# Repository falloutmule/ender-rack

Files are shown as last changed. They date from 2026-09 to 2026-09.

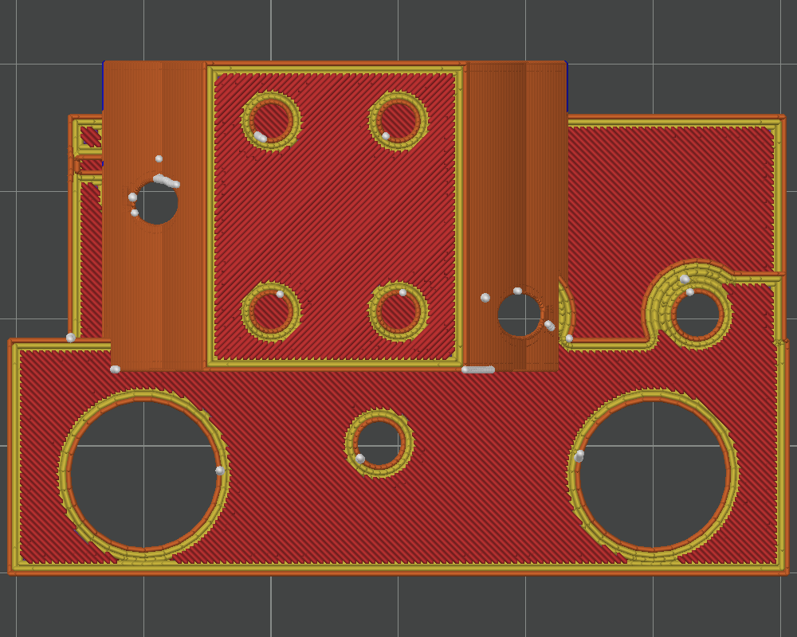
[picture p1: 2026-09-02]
evidence/renders/orca-r5-diagnostic/sliced-preview-top.png

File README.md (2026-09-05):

# EnderRack

EnderRack is an experimental high-lane-count adaptation of the [Annex Engineering TradRack](https://github.com/Annex-Engineering/TradRack) selector architecture to the complete X-axis motion system of an original/older Creality Ender-3-family donor printer.

The intended architecture retains the Ender X extrusion, V-wheel carriage, belt, motor, idler/tensioner, and endstop while replacing the stock TradRack MGN9 selector stage with a custom carriage-to-selector interface. The primary target is 15 lanes at the stock 17 mm TradRack pitch; 12 lanes remains the fallback generated from the same future parametric model.

## Current status

**Experimental. No production-ready release exists.**

The current article is **R7_ARCHITECTURE_V2_Candidate_001**. It has been printed and physically seats on the intact Ender carriage at the observed scope; a recurring boss-clearance overhang print defect did not prevent fit. No TradRack selector has been built yet, so full R7 physical PASS is **not** complete.

Next: [print and assemble the exact stock moving selector](docs/STOCK_SELECTOR_BUILD.md), then finish the R7 physical test. Production work and the 238 mm sweep remain gated. Earlier broad master/reproducibility claims require re-audit under the upgraded FreeCAD skill before production release.

Start with [CURRENT_STATE.md](docs/CURRENT_STATE.md), then read the complete [engineering handoff](docs/ENDER_RACK_HANDOFF.md).

## Validation approach

The project uses a physical-validation-gated workflow:

`reference CAD -> digital correlation -> cheap coupon -> physical PASS -> dependent geometry`

The earlier Ender-3 V2 reference failed this workflow and is archived as rejected evidence. The official original Ender-3 E-plate interface subsequently passed the R2 physical coupon test for the specific features exercised by that coupon.

## Upstream attribution

- [Creality3DPrinting/Ender-3](https://github.com/Creality3DPrinting/Ender-3)
- [Annex-Engineering/TradRack](https://github.com/Annex-Engineering/TradRack)

See [SOURCES.md](sources/SOURCES.md) and [LICENSE_NOTES.md](sources/LICENSE_NOTES.md). Complete upstream archives and assemblies are intentionally not vendored here. No EnderRack-wide license has been selected.

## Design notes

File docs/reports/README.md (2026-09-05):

# Report index

## Current scope

- [R7 V2 physical carriage fit](R7_V2_PHYSICAL_CARRIAGE_FIT.md): scoped owner-observed PASS; full selector fit NOT TESTED.
- [Stock selector build sheet](../STOCK_SELECTOR_BUILD.md) and [source/object evidence](STOCK_SELECTOR_SOURCE_EVIDENCE.json).
- `ENDER3_OFFICIAL_CARRIAGE_COUPON_R2.md`: physical interface evidence at its exercised scope.
- `ENDER3_OFFICIAL_CARRIAGE_REAUDIT.md`: historical reference correlation, subject to current scope and audit caveats.

## Retired design / diagnostic history

`ENDER_RACK_SELECTOR_INTERFACE_COUPON_R5.md`, `LIVE_ORCA_MCP_AUDIT_R5.md` and `legacy/` are historical evidence only. Do not print their G-code or reuse R5/22.25 mm relationships. Current state and upgraded-skill caveats are in [CURRENT_STATE.md](../CURRENT_STATE.md).

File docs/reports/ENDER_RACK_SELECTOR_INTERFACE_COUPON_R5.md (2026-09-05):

> Historical evidence only. Not the current design or print instruction. R5 relationships and 22.25 mm stand-off are retired; see docs/CURRENT_STATE.md.

# EnderRack selector-interface coupon R5

## Status

**DIGITAL PASS — PHYSICAL REAL-SELECTOR TEST REQUIRED**

Fabrication status: **PROVISIONAL — FIT-CHECK FABRICATION ONLY. DO NOT FABRICATE PRODUCTION PARTS.**

R5 supersedes R4. The user-identified failure location was the lateral ligament between the `X=0` wheel-clearance hole and the outside edge. R4 strengthened the lower ligament but accidentally left only approximately 0.25 mm laterally at this exact location.

## Correction

- Wheel-clearance radius: 5.75 mm.
- Minimum material from each wheel relief to its outside X edge: **5.00 mm**.
- Minimum material below each wheel relief: **5.00 mm**.
- R5 X extent: `-10.75 .. +50.75 mm`; the two wheel centers remain `X=0` and `X=40 mm`.
- The two full-height triangular selector-block gussets are retained. They support the cantilevered selector block and address a different load path from the wheel-edge ligament.
- The four selector-block holes remain intentionally blind Ø2.7 × 6.5 mm temporary M3 pilots.

## Verification

| Check | Result |
|---|---:|
| Bounding box | 61.500 × 22.250 × 40.550 mm |
| Volume | 23,459.308 mm³ |
| Topology | One valid solid |
| Circled lateral ligament | 5.000 mm, formerly 0.250 mm |
| Opposite wheel lateral ligament | 5.000 mm |
| Lower wheel ligament | 5.000 mm |
| Selector/coupon intersection | 0.000 mm³ |
| Coupon/wheel-envelope intersection | 0.000 mm³ |
| Coupon/conservative-belt intersection | 0.000 mm³ |
| R2 contact-layer missing volume | 0.000 mm³ |
| STEP BRep distance | 0.000 mm |
| STL bbox maximum delta | 7.63e-7 mm |
| STL facets | 1,520 |

Machine-readable verification: `../../work/ender-rack-inventory/ender_rack_selector_interface_coupon_r5_verification.json`.

## Artifacts

| Artifact | Bytes | SHA-256 |
|---|---:|---|
| `EnderRack_Selector_Interface_Coupon_R5.FCStd` | 17,536,897 | `B1EFD105F3B6D260C9538530F6B6DCBD37D0BAF2DC2C60AE2D66472AFE44FA49` |
| `exports/EnderRack_Selector_Interface_Coupon_R5.step` | 79,900 | `A471DE9772790A6DEC882545069C8CBD4F0CE840D9EA4DB57C37403A67E531C4` |
| `exports/EnderRack_Selector_Interface_Coupon_R5.stl` | 76,084 | `6070C29687531215B4A7D58FBD1C77B53CB3CB9BBB349A0F10DA72946EF2EBAC` |

Evidence renders:

- [Coupon-only isometric](screenshots/EnderRack_Selector_Interface_Coupon_R5_CouponOnly_Isometric.png)
- [Selector-facing](screenshots/EnderRack_Selector_Interface_Coupon_R5_CouponOnly_SelectorFacing.png)
- [Steel-contact](screenshots/EnderRack_Selector_Interface_Coupon_R5_CouponOnly_SteelContact.png)
- [Gusset plan](screenshots/EnderRack_Selector_Interface_Coupon_R5_CouponOnly_GussetPlan.png)

R5 is the current printable CAD source. R4 and earlier revisions are preserved but must not be used for the next fit check.

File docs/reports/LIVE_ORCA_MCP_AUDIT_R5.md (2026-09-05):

> Historical evidence only. Not the current design or print instruction. R5 relationships and 22.25 mm stand-off are retired; see docs/CURRENT_STATE.md.

# EnderRack R5 live Orca MCP slice audit

## Classification

- `LIVE_ORCA_MCP_PASS = PASS`
- `CURRENT_ENDERRACK_TEST_ARTICLE_SLICED = PASS`
- `READY_FOR_PHYSICAL_COUPON_PRINT = NO`

R5 is the only model on the live plate. R4 was explicitly removed before orientation and slicing.

## Source and placement

| Field | Value |
|---|---|
| STL | `C:\Users\fallo\Documents\Codex\2026-08-30\set-up-freecad-mcp-on-this\outputs\ender-rack\exports\EnderRack_Selector_Interface_Coupon_R5.stl` |
| STL SHA-256 | `6070C29687531215B4A7D58FBD1C77B53CB3CB9BBB349A0F10DA72946EF2EBAC` |
| Scale | 100% |
| Rotation | `(90, 0, 0)` degrees |
| World size | 61.500 × 40.550 × 22.250 mm |
| Placement | PASS; broad steel-contact face on bed; overflow 0 mm |

## Profiles and settings

- Printer: `Creality Ender-3 V2 0.4 nozzle`
- Filament: `Creality Generic PLA`
- Process: `0.20mm Standard @Creality Ender3V2`
- 0.20 mm layers; 3 walls; 4 top / 3 bottom layers; 15% crosshatch.
- Generated supports disabled. The retained triangular gussets provide modeled support for the selector-block overhang.
- Auto brim configured; skirt 0.

## Slice result

| Field | Result |
|---|---:|
| State | done, valid, 100% |
| Layers | 111 |
| Time | 1 h 29 m 59 s |
| Filament | 4,300.605 mm / 12.827 g |
| G-code bytes | 2,231,066 |
| G-code SHA-256 | `89EDF29DC7298A7ACCB3A3A6581DD54F20C12D2DCECBDBDB27B11E5AC0F54541` |

G-code: `C:\Users\fallo\Documents\Codex\2026-08-30\set-up-freecad-mcp-on-this\outputs\ender-rack\slice-results\live-orca-mcp-r5\EnderRack_Selector_Interface_Coupon_R5.gcode`.

Renders:

- [Oriented editor view](renders/post-orient-iso/render_plate-0.png)
- [Sliced isometric](renders/sliced-preview-iso/render_plate-0.png)
- [Sliced top](renders/sliced-preview-top/render_plate-0.png)
- [Sliced front/gussets](renders/sliced-preview-front/render_plate-0.png)

## Warning gate

Orca still reports level-3 warning `1000C001` / `bed_temperature_too_high_than_filament` because the native profile sets the bed and PLA vitrification values both to 60 °C. No material temperature was guessed or changed. Therefore this G-code is diagnostic evidence only and `READY_FOR_PHYSICAL_COUPON_PRINT` remains NO until an approved/spool-specific bed temperature is supplied and the part is freshly sliced.

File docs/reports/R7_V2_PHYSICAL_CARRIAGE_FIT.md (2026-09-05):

# R7 V2 scoped physical carriage-fit report

Recorded 2026-09-04 from the owner's direct report. No new photograph, measurement or physical inspection by the agent is claimed.

## Article and scope

`R7_ARCHITECTURE_V2_Candidate_001` has been printed. The Ender donor was NEVER disassembled: original X-axis hardware remains assembled/in place. The print seats on the real Ender carriage and visually aligns correctly. Unsupported boss-clearance overhang defects recurred, but did not prevent the observed carriage fit. No physical stock TradRack selector exists yet.

| Physical item | Result / scope |
|---|---|
| Correct Ender carriage face | PASS, owner-observed |
| R7 seats on real carriage | PASS, owner-observed |
| Exercised carriage hole relationship | PASS, observed scope only |
| Visible wheel-fastener relationship | PASS, observed scope only |
| Boss clearance sufficient for seating | PASS, observed scope only |
| Boss-clearance unsupported-overhang print quality | DEFECT NOTED; not a seating failure |
| Selector-side fit | NOT TESTED |
| Belt/clamp dynamic clearance | NOT TESTED |
| Selector rocking/translation/rotation | NOT TESTED |
| Physical stand-off / tool access / loaded stiffness | NOT ESTABLISHED by this report |
| Full R7 physical PASS | NOT YET |

## Digital record before printing — not a new certification

- v0.2: 19/19 checks PASS.
- Candidate installed-selector check: no positive-volume interference reported for evaluated valid geometry; invalid source gear remained UNVERIFIED.
- Cable-cover nominal CAD clearance: 2.950 mm.
- Left selector-body nominal CAD clearance: 2.211 mm.
- Minimum window-to-pilot material: 0.975 mm, not certified strength.
- Candidate signed stand-off: +15.0 mm; NOT physically validated.

Evidence: local `outputs/ender-rack-r7-architecture-v2-20260904/manifest.json`. Hashes below identify the staged article files at documentation time. The owner's identification of the exact printed candidate is accepted; this is not independent proof that a particular G-code file was executed.

| Staged artifact | SHA-256 |
|---|---|
| `EnderRack_R7_ARCHITECTURE_V2_Candidate_001.step` | `211dd737f815708c13a3b893db18f45a31397b28b6dba2ba8a8c46da538f51cc` |
| `EnderRack_R7_ARCHITECTURE_V2_Candidate_001.stl` | `3f976add9b47ac424422b241242a32665b2b3c038427b2abf115d3fc5488bbd3` |
| `EnderRack_R7_ARCHITECTURE_V2_Candidate_001_E_PLATE_FACE_DOWN.step` | `a7f6751d69ed0f7f1a405b19c930a977331c63427a5b542f0489232f2b75046b` |
| `EnderRack_R7_ARCHITECTURE_V2_Candidate_001_E_PLATE_FACE_DOWN.stl` | `ed7fb8c7fa278a73bb028d01aa4eb59f7af653fbbaf37fdf5f1b80f93a545afd` |
| `EnderRack_R7_ARCHITECTURE_V2_Candidate_001_Voxelab_Aquila_0p4_PLA_220C_55C.gcode` | `ef1b904e6d0c422540dd8a2c84c911b99e0e558ad9afdffdc095a9fb02fee2b1` |

## Upgraded-skill audit caveat

FreeCAD skill commit `7c26a143d2a6e4318724b96cc71c297f7424efa0` found stale embedded context metadata, 48 unreconciled shape occurrences, hidden live-session generator dependencies and ineffective declared parameters. Earlier broad reproducibility/whole-assembly claims require re-audit before production. This task did not redo that audit. These findings neither erase the owner's physical fit observations nor make untested selector behavior PASS.

## Repository baseline and scope

At task start the original checkout and current remote main were both `3e33980e440dbcbaa9c4284f37c8e8d96db4fa81` (observed, not imposed). Original checkout had unstaged `.gitignore`, `README.md`, `docs/CURRENT_STATE.md`, `docs/DECISIONS.md`, `docs/ENDER_RACK_FRESH_THREAD_PROMPT.md`, `docs/ENDER_RACK_HANDOFF.md`, and untracked `tools/`, `verification/`. No staged edits were observed.

A fresh clone of actual current remote main was used for this documentation update, preserving that original checkout and all its unfinished verifier/tool work. No reset, history rewrite, old-baseline checkout or CAD modification. This commit documents the true state; it does not represent unreviewed local tool changes as released software. R7 design files remain staged externally, identified by hashes rather than silently regenerated.

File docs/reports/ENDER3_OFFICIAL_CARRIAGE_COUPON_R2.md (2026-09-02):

# Ender-3 Official Carriage Coupon R2

## Status

**PHYSICAL FIT-CHECK PASS — 2026-09-01**

Fabrication status: **PROVISIONAL — FIT-CHECK FABRICATION ONLY. DO NOT FABRICATE PRODUCTION PARTS.**

The R1 coupon established good physical hole-pattern correlation but could not seat flat because it omitted relief for the two retained, raised hotend bosses. R2 changes only the coupon thickness and adds two coaxial boss pockets. The official plate reference, hole centers, wheel reliefs, V-notch, and motor-side cross are unchanged.

## Controlling dimensions

| Parameter | Value | Source |
|---|---:|---|
| Boss count | 2 | Physical observation / official assembly correlation |
| Boss center spacing | 14.000 mm | Official `E plate` BRep |
| Nominal boss-envelope input | 5.000 × 5.000 mm | Successful R2 design input; not an independent boss measurement |
| Pocket diameter | 5.500 mm | R2 geometry physically passed |
| Pocket depth | 5.200 mm | R2 geometry physically passed |
| Remaining floor | 1.200 mm | Fit-check design parameter |
| Coupon thickness | 6.400 mm | Pocket depth + floor |
| Through holes | Ø3.400 mm | Unchanged from R1 |

The physical seating result controls R2. The actual boss diameter and height were not independently measured, so the bosses remain clearance features rather than precision locators.

## Deliverables and verification

| Artifact | Bytes | SHA-256 |
|---|---:|---|
| `Ender3_Official_Carriage_FitCheck_R2.FCStd` | 27,839 | `5BFCCEA429CA99938D7D4C6E331EAB8527BCAC78F001BD873B6BBEB9D56F6B39` |
| `exports/Ender3_Official_Carriage_FitCheck_R2.step` | 43,823 | `CEB0FF7112BBFD7E4EDBA46C828C431A68E6472DCBF275925C5A48B8941B4AFC` |
| `exports/Ender3_Official_Carriage_FitCheck_R2.stl` | 46,284 | `E57E049BD18FC0F773B481B130ADC6976BBFF6C08E0909EE653916B485F3D88B` |
| `screenshots/Ender3_Official_Carriage_FitCheck_R2.png` | 21,190 | `52B99C8099405AFC99566D720B2FF6B1E23C5563844029B8EB56C96636DDB788` |

| Check | Result |
|---|---:|
| Bounding box | 56.500 × 32.900 × 6.400 mm |
| Topology | PASS — one valid solid |
| Save/close/reopen/recompute | PASS |
| Parameter object persisted | PASS |
| Reopened BRep pocket cylinders | PASS — 2 × R2.750, Z=0.000–5.200 mm |
| STEP BRep distance | `9.53e-17 mm` |
| STEP maximum bounding-box delta | `2.84e-14 mm` |
| STL maximum bounding-box delta | `5.72e-7 mm` |
| STL facets | 924 |
| RPC binding during generation | PASS — `127.0.0.1:9875` only |

Machine-readable verification: `../../work/ender-rack-inventory/ender3_official_fitcheck_r2_verification.json`.

## Print and physical test

Print the STL in PLA with a 0.4 mm nozzle and 0.2 mm layers. Import at 100% scale with no initial XY or hole compensation. Flip the part in the slicer so the two boss pockets face upward.

1. Put the V-notch toward the idler/tensioner side and the engraved cross toward the motor side.
2. Confirm both retained bosses enter the pockets without force.
3. Confirm all four pattern holes remain aligned.
4. Confirm the coupon seats flat against the steel face without rocking.
5. Hold or tighten it finger-snug and verify the datum marks cannot translate or rotate appreciably.
6. Confirm the wheel and separate gold belt hardware remain clear.

All six checks were reported as passing. The exact FCStd/STEP/STL and the received PASS photograph are preserved under `validated/ender3-carriage-interface-r2-pass/` with SHA-256 hashes.

No adapter, tensioner, selector transform, lane model, or production component was changed.

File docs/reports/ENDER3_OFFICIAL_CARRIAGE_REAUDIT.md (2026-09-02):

# Ender-3 Official Carriage Re-audit

## Superseding physical result — 2026-09-01

**R2 PHYSICAL FIT-CHECK PASS.** The official E plate is promoted as the controlling fabricated-fit reference only for the hole pattern, seating face, orientation, and boss-clearance relationship exercised by R2. The exact successful artifacts and PASS photograph are preserved under `validated/ender3-carriage-interface-r2-pass/`.

The R2 pockets are Ø5.5 × 5.2 mm deep. The 5 × 5 mm derivation values are successful nominal coupon inputs, not independently measured boss dimensions. The bosses are clearance features, not precision locators.

Static selector-interface work has resumed in `EnderRack_Selector_Interface_Coupon.FCStd`; physical real-selector testing is the current release gate. The historical re-audit narrative below is retained for traceability.

## Outcome

**PASS — the new physical photograph visually correlates with the official Creality Ender-3 `E plate` and complete carriage assembly when the correct plate face and orientation are used.**

This supersedes the earlier visual rejection. That rejection compared the wrong/opposite face and treated separate assembly hardware as if it had to be topology of the bare plate.

The official carriage remains at **physical fit-check candidate** status. R1 confirmed the hole pattern but failed to seat because it omitted relief for the two retained hotend bosses. Production adapter work remains blocked until the R2 coupon passes on the real machine.

## R1 physical result and R2 recovery — 2026-09-01

New physical evidence establishes a narrower result than either the original rejection or an unconditional pass:

- R1 official-CAD hole-pattern correlation: **PASS**;
- R1 flat seating: **FAIL — two retained raised hotend bosses obstruct the coupon**;
- boss removal: **not authorized**; they are treated as integral/retained carriage features;
- user-measured boss size: **Ø5.0 × 5.0 mm high**;
- gold belt hardware: separate assembly components, unchanged;
- R2 digital model/export validation: **PASS**;
- R2 physical seating: **PENDING**.

R2 adds two Ø5.5 × 5.2 mm-deep pockets on the same 14.0 mm source-derived centers. A 1.2 mm floor produces a 6.4 mm coupon thickness. Hole centers, Ø3.4 mm bores, wheel reliefs, outline, and datum marks are unchanged. See `ENDER3_OFFICIAL_CARRIAGE_COUPON_R2.md`.

## Physical evidence

Evidence file: `interface-recovery/evidence/physical_plate_rear_2026-08-31.jpg`

SHA-256: `AA6078E69A8E5B0F2A0D393312A3B4198EC32DB7804CC294B9D424CF7C9D427F`

The photograph is perspective evidence rather than a calibrated dimensional image. It supports correspondence of:

- overall rounded rectangular outline and central wheel tab;
- three-wheel triangular pattern;
- two 14 mm-spaced hotend-mount features;
- asymmetric auxiliary holes;
- wheel fasteners;
- two gold rear raised components associated with the belt.

## Face and orientation correspondence

| Physical/CAD view | Correspondence |
|---|---|
| Photograph | Rear / wheel-and-belt face of the physical carriage, with the central wheel tab upward |
| Imported model | `Part__Feature286`, label `E plate` |
| Matching CAD camera | Top view of the imported assembly with a 180° in-plane roll |
| Opposite face | Bottom view; hotend/radiator attachment face |

The combined render is [Ender3_Official_Carriage_FRONT-left_REAR-right.png](screenshots/Ender3_Official_Carriage_FRONT-left_REAR-right.png): **front is left; rear/photo-corresponding face is right**.

Individual renders:

- [Front / hotend face](screenshots/Ender3_Official_Carriage_FRONT_PhotoOrientation.png)
- [Rear / photo-corresponding face](screenshots/Ender3_Official_Carriage_REAR_PhotoOrientation.png)

## Complete-assembly feature audit

The apparent raised features are split between integral plate topology and separate assembly components:

| Feature | Official object(s) | Finding |
|---|---|---|
| Bare steel plate | `Part__Feature286` / `E plate` | One valid solid; controls fabricated-fit hole positions and plate outline |
| Two 14 mm-spaced hotend mounting bosses | Integral faces of `E plate` | Embossed/counterbored plate topology, not separate standoff objects |
| Hotend/radiator attachment screws | `Part__Feature663`, `Part__Feature664` | Separate `M3X16 Pan Head Screw003/004` objects inside `Sprinkler_assembly`; aligned to the integral boss centers |
| Gold raised rear pieces | `Part__Feature631`, `Part__Feature632` | Separate `Copper cover002/003` belt-end/crimp hardware; not hotend standoffs |
| Wheel hardware | `Part__Feature287–293`, `384–386` | Separate screws, washer, eccentric column, spacers, and nuts |

The official hotend-mount center spacing is exactly `14.000 mm`. The upper wheel-axis spacing is `40.000 mm`, and the eccentric axis is `40.200 mm` from the upper-wheel line.

Detailed machine-readable results: `../../work/ender-rack-inventory/ender3_official_carriage_reaudit.json`.

## Official-CAD fit-check coupon

Generated through FreeCAD MCP directly from cylindrical faces of the imported `E plate` BRep:

- `Ender3_Official_Carriage_FitCheck.FCStd`
- `exports/Ender3_Official_Carriage_FitCheck.step`
- `exports/Ender3_Official_Carriage_FitCheck.stl`
- [Coupon render](screenshots/Ender3_Official_Carriage_FitCheck.png)

The coupon is a rear-face pattern overlay, not an adapter. It contains:

- both 14 mm-spaced hotend-mount holes;
- both asymmetric auxiliary holes visible in the official plate pattern;
- reliefs derived from the installed upper-wheel fastener envelopes;
- a V-notch marking the official idler/tensioner side;
- an engraved cross marking the official motor side;
- no TradRack, selector, tensioner, or production structure.

Dimensions and digital verification:

| Check | Result |
|---|---:|
| Coupon bounding box | 56.500 × 32.900 × 2.000 mm |
| Selected source-derived holes | 4 |
| Nominal source bores | Ø3.000 mm |
| Printed clearance bores | Ø3.400 mm |
| Upper-wheel hardware relief radius | 5.750 mm |
| Coupon topology | PASS — one valid solid |
| Save/close/reopen/recompute | PASS |
| STEP BRep distance from FCStd | `7.42e-14 mm` |
| STEP maximum bounding-box delta | `2.84e-14 mm` |
| STL maximum bounding-box delta | `5.72e-7 mm` |
| STL facets | 716 |

Hashes:

| File | Bytes | SHA-256 |
|---|---:|---|
| `Ender3_Official_Carriage_FitCheck.FCStd` | 24,627 | `C4175A7755547D9A2DB97604E42E94CEBF9F6A8A2A187A6B5E917BBEA12FC36B` |
| `Ender3_Official_Carriage_FitCheck.step` | 40,021 | `900BCF148CB706E4676D125A6EC9DDD5D4752B4ED1A51B1910FBE4BFE2A1C3CD` |
| `Ender3_Official_Carriage_FitCheck.stl` | 35,884 | `946469AD81B78B434278A1850FFD6336486A68D2CAEA35CC339B86701350E609` |

Machine-readable verification: `../../work/ender-rack-inventory/ender3_official_fitcheck_verification.json`.

## R2 physical fit-check instructions

Fabrication status: **PROVISIONAL — FIT-CHECK FABRICATION ONLY. DO NOT FABRICATE PRODUCTION PARTS.**

Do not reprint R1. Print `exports/Ender3_Official_Carriage_FitCheck_R2.stl` cheaply in PLA with a 0.4 mm nozzle and 0.2 mm layers. Do not apply slicer XY/hole compensation on the first test. Import at 100% scale and flip the part so the two boss pockets face upward.

Test against the same rear/photo-corresponding face used for the re-audit:

1. Orient the V-notch toward the official idler/tensioner side and the engraved cross toward the motor side.
2. Confirm both retained bosses enter the new pockets without force.
3. Confirm the two large open reliefs clear the installed upper-wheel fastener hardware.
4. Confirm both hotend-mount holes align and accept pins/fasteners finger-snug without forcing.
5. Use the two auxiliary holes as positional pattern checks; do not assume they are threaded or force fasteners into them.
6. Confirm the coupon seats flat without rocking.
7. With the coupon held finger-snug, confirm the V-notch/cross cannot translate or rotate appreciably relative to the wheel-axis pattern.

PASS promotes the official `E plate` to the EnderRack carriage reference. FAIL stops adapter work and requires recording the exact R2 interference and remeasuring the controlling feature before any geometry is changed.

No `EnderRack_15Lane_Ender3.FCStd`, production adapter, or tensioner redesign was created during this re-audit.

## Project state

**ENDER RACK ARCHITECTURE PRESERVED — R1 HOLE PATTERN PASS / BOSS SEATING FAIL — R2 DIGITAL PASS — R2 PHYSICAL FIT-CHECK PENDING**

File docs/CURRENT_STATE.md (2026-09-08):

# EnderRack current state

Updated 2026-09-07. **Current article: R7_ARCHITECTURE_V2_Candidate_001. Printed; scoped carriage fit PASS; full R7 physical PASS NOT YET. Controlling selector remains stock TradRack R1.**

## Physical state — owner report

The Ender donor was NEVER disassembled. Original Ender X-axis hardware remains assembled/in place. The exact R7 V2 print seats on the real Ender carriage and visually aligns correctly. The boss-clearance unsupported-overhang print defect recurred but did not prevent observed seating. No physical TradRack selector has been built yet.

Correct carriage face, seating, exercised carriage-hole relationship, visible wheel-fastener relationship, and boss-clearance seating function PASS only at the observed scope. Selector fit, belt/clamp dynamic clearance, rocking/translation/rotation and complete physical validation are NOT TESTED. See [scoped physical report](reports/R7_V2_PHYSICAL_CARRIAGE_FIT.md).

## Recorded digital state before printing

Verifier v0.2: 19/19 checks PASS. The candidate's complete installed selector check reported no positive-volume interference among evaluated valid geometry; invalid source gear remained UNVERIFIED. Cable-cover nominal clearance 2.950 mm; left body 2.211 mm; minimum window-to-pilot material 0.975 mm. These are recorded CAD results, not physical measurements or strength proof. Stand-off +15.0 mm remains a candidate relationship.

## Audit caveat

Installed upgraded FreeCAD skill: commit `7c26a143d2a6e4318724b96cc71c297f7424efa0`. Earlier broad master-context/reproducibility claims preceded discovery of stale embedded context metadata, 48 unreconciled shape occurrences, hidden live-session generator dependencies and ineffective declared parameters. Those claims require re-audit before production release. The audit caveat does not erase observed physical carriage fit or promote invalid geometry to clear. No whole-master re-audit was performed for this selector-build task.

## Immediate next action

Build the exact [stock moving selector](STOCK_SELECTOR_BUILD.md), then finish R7's physical test. The [Binky/EREC comparison](MODDED_SELECTOR_COMPARISON.md) did not establish an evidence-complete modded R7 relationship: the primary Fusion assembly cannot be authoritatively decoded in FreeCAD, and the STEP fallback contains an invalid encoder-left body overlapping the R7 region. Stock remains controlling; R7 remains frozen. Measure the spare Ender stepper and both mirrored BMG-clone internals before buying replacements.

R7 architecture/frame, four selector axes and +15 mm candidate placement remain frozen. R5 and its 22.25 mm relationship are retired. R6/R6R1 geometries are rejected. R6R2 DIGITAL_OBJECT PASS; PHYSICAL TEST WAIVED BY OWNER, NOT A PHYSICAL PASS. Historical solids are evidence, not construction inputs.

## Downstream gate

Full R7 physical PASS precedes production adapter and full 238 mm selector sweep. Fifteen lanes at 17 mm pitch remains the goal; twelve lanes the fallback. First/middle/last master positions were context views, not a validated sweep. No redesign, slicing, printing command, production work or sweep was performed in this documentation task.

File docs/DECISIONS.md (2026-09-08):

# EnderRack durable decisions

Current as of 2026-09-07; supersedes conflicting historical status language, not historical evidence.

1. Mechanical donor is the original/older Ender-3-family X-axis. It was NEVER disassembled. Aquila identifies the print machine only.
2. Community Ender-3 V2 fit geometry is retired. Official Creality E-plate + scoped R2 physical evidence establish the interface and seating face.
3. Preserve interfaces, physical facts and known failures independently from disposable coupon solids. Required empty clearances do not require reproducing R2 pocket shelves.
4. R5 wrong-face relationship, 22.25 mm stand-off and legacy V-notch are retired. R6/R6R1 architecture is rejected. R6R2 digital PASS has an owner-waived physical witness, never physical PASS.
5. Current article is R7_ARCHITECTURE_V2_Candidate_001, with two named exterior-open access windows, fixed selector axes/orientation and +15 mm candidate stand-off. This documentation task changes no geometry.
6. R7 V2 is printed and passes the observed carriage seating/interface scope. Unsupported boss-clearance overhang print quality is defective but did not prevent seating. No selector exists physically; full R7 physical PASS is outstanding.
7. Keep digital checks, construction assertions, physical evidence and audit caveats separate. An invalid source gear stays UNVERIFIED, never zero collision. Earlier broad master reproducibility claims need the upgraded-skill re-audit before production.
8. The 0.25 mm demonstrated weak-ligament failure is known bad; 5 mm is a design preference, not an invented universal minimum. A passing STEP is not strength proof.
9. Use existing verifier v0.2 only for its supported operators. No verifier expansion, CAD redesign or audit rerun in this selector-build task.
10. Build one stock default moving selector: 9 mm C-cart middle, 10x10 two-hole right, Micro-Fit wiring holder, FT1117M servo and conventional BMG filament-drive mechanism. Keep the filament-drive motor; omit the replaced stock MGN translation system.
11. Source authority is pinned TradRack `f89dc0b115adfc49195d782c5d7ecd348a574891`, its default STEP, STL files and official manual; the linked live BOM snapshot is separately dated/hashed. Unresolved discrepancies must remain visible.
12. Stock selector printing follows upstream ASA/PC guidance, not PLA coupon settings. R7 service sequence: mount/tighten carriage adapter first, then mount selector finger-snug using verified engagement.
13. Full R7 physical PASS gates production adapter and 238 mm sweep. Target 15 lanes at 17 mm pitch; 12-lane fallback. Context lane views are not a collision sweep.
14. Read actual repository HEAD/dirty state; preserve user work and history. Happy Hare/Klipper and donor electronics remain future plans, not commissioned hardware.
15. The 2026-09-07 Binky/EREC comparison does not change the controlling selector. Printables 1385926 is the preferred physical-build mod candidate, but its F3D cannot be decoded into authoritative assembly BReps/placements by the installed FreeCAD toolchain. Printables 963410 shows positive nominal clearance for valid Binky/cutter bodies, but an invalid overlapping encoder-left body keeps the complete result UNVERIFIED. Preserve this result; do not infer clear from invalid geometry.
16. Build stock R1 first. Before buying a filament-drive motor or genuine Bondtech internals, measure the spare Ender stepper and both mirrored BMG-clone internals. Housing handedness is not a reason to reject reusable internals.

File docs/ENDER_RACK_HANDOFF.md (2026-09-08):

# EnderRack engineering handoff

Read [CURRENT_STATE.md](CURRENT_STATE.md), [R7 V2 physical report](reports/R7_V2_PHYSICAL_CARRIAGE_FIT.md), [modded-selector comparison](MODDED_SELECTOR_COMPARISON.md), then [STOCK_SELECTOR_BUILD.md](STOCK_SELECTOR_BUILD.md).

## Controlling facts

- Original/older Ender-3-family mechanical donor: intact X-axis, never disassembled. Aquila is the coupon print machine, not the mechanical reference.
- Official Creality E-plate and scoped R2 physical interface evidence establish the carriage interface. Preserve its established physical face correlation.
- ENDER_INTERFACE v1 and authenticated stock TradRack selector interface are the inputs; historical coupon solids are evidence only.
- R7_ARCHITECTURE_V2_Candidate_001 has been printed and fits the carriage at the owner-observed scope. Its recurring boss-clearance overhang defect is recorded, not redesigned here.
- No stock selector exists physically yet. Build the resolved 9 mm C-cart / 10x10-right / Micro-Fit / FT1117M moving selector, excluding the replaced stock MGN motion stage.
- Stock R1 remains controlling after the Binky/EREC comparison. Modded R7 compatibility is UNVERIFIED, not failed-clear: the preferred F3D cannot be placed authoritatively in FreeCAD and the STEP reference contains an invalid encoder-left body in the R7 region.
- Measure spare Ender stepper and both mirrored BMG-clone internals before buying the filament-drive motor or genuine Bondtech parts.
- +15.0 mm selector stand-off is candidate, not measured/validated. Full R7 physical PASS has not occurred.

## Preserve architecture and evidence

R7 V2 has two named exterior-open carriage-access reliefs and one main load path. Do not silently change topology, pilots, orientation, base or stand-off. No historical coupon contours as construction input. The 5 mm clearance preference is not a fabricated physical requirement; the 0.975 mm reported minimum window-to-pilot material is not a strength certification.

The prior 19/19 v0.2 result and valid-component clearance findings are historical digital evidence. Invalid source gear remains UNVERIFIED. Upgraded skill `7c26a143d2a6e4318724b96cc71c297f7424efa0` identified stale master metadata, 48 unreconciled occurrences, live-session dependencies and ineffective parameters. Re-audit broad reproducibility/whole-assembly claims before production, without erasing the scoped physical result.

## Next physical sequence

Assemble the stock moving selector from the build sheet. Tighten R7-to-Ender fasteners before installing the selector. Determine safe selector screw engagement; finger-snug only. Record all R7 physical checks, including actual stand-off, motion of the mounted joint and real hardware/tool clearances. No powered commissioning yet. R7 physical PASS unlocks production adapter and 238 mm sweep; context views do not unlock them.

## Repository handling

Always read actual HEAD and dirty state; do not reset to a remembered baseline. The 2026-09-04 documentation update was made in a clean current-remote clone to preserve pre-existing verifier/tool edits in the original dirty checkout. See the physical report for baseline and change scope. Upstream TradRack remains pinned to `f89dc0b115adfc49195d782c5d7ecd348a574891`; do not casually update CAD or variants.

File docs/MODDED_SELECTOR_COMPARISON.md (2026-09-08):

# Modded selector comparison

Updated 2026-09-07. **Selected build: authenticated stock TradRack R1 moving selector.** The Binky and EREC/cutter variants remain useful future options, but neither has an evidence-complete R7 compatibility result. R7 geometry was not changed.

Repository baseline before this comparison update: `875ec737eb1b558d64b7c11aca0a0677c10a04d2`, clean working tree. History was not reset or rewritten.

## Decision

| Option | Evidence | R7 result | Decision |
|---|---|---|---|
| A. Stock TradRack R1 | Pinned upstream default STEP, pinned STLs, official BOM/manual; existing complete-selector R7 check | DIGITALLY COMPATIBLE at the recorded candidate relationship; invalid stock gear remains UNVERIFIED; physical selector test outstanding | **BUILD THIS** |
| B. R1 + Binky | Printables 963410 complete STEP reference; valid Binky bodies evaluated in the stock-R1 frame | **UNVERIFIED**: Binky rack clears R7 by 3.030 mm and valid encoder-right body by 1.874 mm, but encoder-left is an invalid source BRep whose bounding box overlaps the R7 region | Do not print as the controlling selector |
| C. R1 + Binky + EREC cutter | Printables 1385926 editable Fusion source and physical-build evidence; 963410 STEP reference; 985791 STL cutter evidence | **UNVERIFIED**: primary Fusion archive cannot be decoded into authoritative BReps/placements by the installed FreeCAD toolchain; fallback STEP retains the invalid overlapping encoder-left body. Valid cutter-reference bodies did not positively intersect R7; one modeled MG996R servo body is only 0.172 mm clear | Do not print as the controlling selector |

This is not a physical PASS for any selector. The existing R7 carriage-side fit remains scoped physical evidence only.

## Sources inspected

- Official authority: Annex Engineering TradRack commit `f89dc0b115adfc49195d782c5d7ecd348a574891`, `CAD/Trad_Rack_R1_2024-03-04_STEP.7z` -> `trad_rack_(default).STEP`.
- Primary mod candidate: [TradRack Binky+EREC Integration](https://www.printables.com/model/1385926-tradrack-binkyerec-integration-trianglelabs-partne), RedHeadnDead, CC BY, published 2026-04-26. It supplies 17 STL files and `Tr-B-EREC.f3d` (`a8720d880db6ff864ebedba0aa5a94ab2e2b68de9ed46b5c23b8c72be6046d12`). The author reports a physical build and describes a stronger Binky mount, removable Binky/EREC, a larger selector servo, and an inverted EREC gear assembly.
- Assembly-CAD reference: [TradRack MMU + Binky + Filament Cutter + User Mods CAD Model](https://www.printables.com/model/963410-tradrack-mmu-binky-filament-cutter-user-mods-cad-m), BakedBean3D, GPL-2.0. It supplies Binky-only and Binky+EREC STEP assemblies. Its author explicitly says the modeled Binky integration was not printed or used.
- Cutter implementation evidence: [TradRack Encoder + Cutter Mod](https://www.printables.com/model/985791-tradrack-encoder-cutter-mod), Pham Tuan, GPL-2.0. It supplies STL variants, not an editable/assembled source; the page identifies a retained gate switch, V/623 encoder options, EREC integration, and changed cable position.
- Binky upstream: Marc Neuhaus's `EnragedRabbitProject/usermods/Binky`. Binky replaces the optical encoder with an EE-SX398-based PCB and filtered slotted wheel, using a BMG idler gear, its needle bearings and 3 x 20 mm pin. It remains mounted on the moving selector and adds a three-wire encoder connection.
- Cutter upstream: KevinAkaSam/BioKeks EREC Beta 7.0. It is a servo-actuated, selector-mounted inline cutter behind the encoder. A scalpel/Exacto blade sits on a swinging arm carrying the ECAS fitting; opening permits tip feed, closing cuts, and the separated tip falls out. Happy Hare requires its EREC add-on configuration and cutter action; firmware commissioning is later work.

The repository [source manifest](reports/MODDED_SELECTOR_SOURCE_MANIFEST.json) anchors the official files and principal assemblies. The complete 44-file Printables inventory, including every STL hash and file ID, is preserved in external scratch as `source_provenance_manifest.json` beside the downloaded sources.

## Frame and R7 check

The mod reference was correlated to stock R1 first, then carried through the existing stock-R1-to-E relationship. No independent Ender face was inferred.

`T_E<-MOD`, millimetres, column-vector convention:

```text
[ 1  0  0  -20.375000000 ]
[ 0  0  1   25.022256770 ]
[ 0 -1  0  -52.031656654 ]
[ 0  0  0    1.000000000 ]
```

The rotation is orthogonal, right-handed, determinant +1, unit scale and no shear. It maps the modded 9 mm/C-cart middle-carriage reference back to the authenticated stock selector frame; R7 remains at +15.0 mm candidate stand-off with its four frozen pilot axes.

### Numeric evidence

| Reference occurrence | Source validity | R7 intersection | R7 distance | Disposition |
|---|---:|---:|---:|---|
| `BinkyRack wgate switch encoder mount (Exerqtor_82339)` | valid | 0.000 mm3 | 3.030 mm | clear in this reference placement |
| `Encoder Right (2)(Mirror)` | valid | 0.000 mm3 | 1.874 mm | clear, small nominal margin |
| `Encoder Left (2)(Mirror)` | **invalid** | not evaluated as zero | overlapping bounding region | **UNVERIFIED** |
| EREC/cutter valid bodies | valid | no positive-volume R7 intersection found | nonblocking except servo below | reference only |
| `servoMotorMG996R (1)(Mirror)` | valid | 0.000 mm3 | 0.172 mm | technically clear, not a practical validated margin |

Stock MGN carriage, rail screws and lane-module occurrences present in the reference STEP were excluded because EnderRack replaces that translation system. They are not selector collisions. Unchanged stock selector geometry uses the authenticated official R1 source rather than invalid duplicate imports from the community STEP.

The result is not promoted to `MODDED SELECTOR / R7 INTERFACE DIGITALLY COMPATIBLE`: the invalid encoder-left source body overlaps the only region where a collision would matter. Kernel/source failure is UNVERIFIED, never zero.

## Part replacement map

The primary mod's native assembly membership cannot be recovered from the F3D without Autodesk ShapeManager support. Filename-only mappings below are intentionally not promoted to authoritative replacements.

| Official R1 part | Primary mod evidence | Status |
|---|---|---|
| cable cover | `[a] Tr-B-EREC_Cable Chain Mount.stl`; no stock-named cable cover supplied | replacement relationship **UNRESOLVED** |
| carriage left | `Tr-B-EREC_Carriage - Left.stl`, `Carriage - Left Arm.stl` | MODIFIED/REPLACED family; exact occurrence split UNRESOLVED |
| carriage middle, 9 mm/C-cart | `Tr-B-EREC_Carriage.stl` | likely modified integration body, but pilot/mating correspondence **UNVERIFIED** |
| carriage right, 10x10 | `Carriage - Right Arm.stl`, cable-chain mount | MODIFIED/REPLACED family; exact 10x10 correspondence **UNVERIFIED** |
| Micro-Fit holder | no unambiguous matching mod file | UNRESOLVED; do not infer removal |
| servo horn | `[a] Tr-B-EREC_Servo Horn.stl` plus selector servo spacers/cage | REPLACED for larger-servo design |
| arm; gear casings left/right; motor plate; NEMA17 spacer; tensioner collar | no replacements supplied by name | stock carry-over is plausible from author instructions, but assembly membership UNVERIFIED |
| filament-drive NEMA17 and conventional BMG drive | author says follow TradRack BOM; no replacement motor-drive file | unchanged function; exact hardware envelope UNVERIFIED |
| Binky encoder | encoder left/right, Binky PCB/slotted wheel implied by source description | ADDED on moving selector |
| EREC cutter | cutter arm, servo gear/rig/cage, tip catcher | ADDED inline cutter architecture |

## What Binky adds

Binky provides direct filament-motion feedback with a slotted wheel and filtered optical PCB. It adds encoder wiring and changes the moving-selector/cable envelope. The standard Binky mechanism uses BMG-style idler components, so parts from the two mirrored BMG clones are worth measuring. Housing handedness alone does not disqualify internals. Binky is not selected yet because the complete R7 relationship remains UNVERIFIED.

## What the cutter adds

EREC Beta 7 adds a second servo, printed cutter/encoder support, servo gear, swinging ECAS cutter arm, blade, fasteners/inserts and a tip catcher. It adds a blade consumable, debris path, cable load and Happy Hare add-on configuration. It is not required to establish initial stock EnderRack operation, and its integration changes the selector envelope checked by R7.

## Build selection and next action

Print and build the exact stock R1 selector in [STOCK_SELECTOR_BUILD.md](STOCK_SELECTOR_BUILD.md). First measure the spare Ender stepper and both mirrored BMG clones using the reuse checklist in that document; do not buy the filament-drive motor or genuine Bondtech internals until those measurements are compared. Mount the completed stock selector finger-snug to the already printed R7 and finish the physical R7 checklist before selecting Binky, cutter, production adapter or the 238 mm sweep.

## External inspection artifacts

The source downloads, complete provenance manifest, comparison FCStd and four rendered views are staged outside the Git tree at:

`C:/Users/fallo/Documents/Codex/2026-09-02/files-pasted-by-the-user-continue/EnderRack-Modded-Selector-Comparison-20260907/`

The FCStd is a viewing derivative, not source authority. R7 is frozen; stock R1 is blue, Binky is orange, EREC is purple, and invalid source bodies are red.

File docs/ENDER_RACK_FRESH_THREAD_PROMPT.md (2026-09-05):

# Fresh-thread handoff

Continue EnderRack by first reading CURRENT_STATE.md, ENDER_RACK_HANDOFF.md, reports/R7_V2_PHYSICAL_CARRIAGE_FIT.md and STOCK_SELECTOR_BUILD.md. Read actual Git HEAD and dirty state; preserve edits and history.

The Ender X-axis is intact and was never disassembled. R7 V2 Candidate001 is printed and physically seats at the observed carriage scope, with a recurring unsupported-overhang defect. The stock selector has not been built. Full R7 physical PASS is NOT YET. Preserve frozen R7 architecture and +15 mm candidate relationship. Do not resume retired R5 geometry, 22.25 mm assumptions or a coupon slicing task.

Build the stock selector from pinned source evidence, resolving the explicit procurement/engagement caveats before dependent assembly. No production or 238 mm sweep before full R7 physical PASS. Earlier whole-master/reproducibility claims require upgraded-skill re-audit before production, not erasure of physical observations.

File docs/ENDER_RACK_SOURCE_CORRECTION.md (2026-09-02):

# EnderRack Source Correction

## Superseding milestone — 2026-09-01

**OFFICIAL ENDER-3 CARRIAGE INTERFACE — PHYSICAL R2 FIT-CHECK PASS**  
**15-LANE ENDER RACK — STATIC SELECTOR INTERFACE DESIGN RESUMED**

The exact successful R2 FCStd/STEP/STL and physical PASS photograph are preserved under `validated/ender3-carriage-interface-r2-pass/`. The official E plate now controls fabricated fit only for the physically validated hole pattern, seating face, orientation, and boss-clearance relationship. Bosses remain clearance features rather than locating datums.

`EnderRack_Selector_Interface_Coupon.FCStd` is the new static secondary coupon. It digitally passes reopen/export and local selector/wheel/conservative-belt checks. Physical real-selector testing is now the release gate. See `ENDER_RACK_SELECTOR_INTERFACE_COUPON.md`. No 238 mm sweep, lane structure, tensioner redesign, or production adapter was generated.

## Current project state

Historical state below is retained for traceability; it is superseded by the milestone above.

The Ender-3 V2 carriage reference remains rejected. The real plate corresponds closely to the official `E plate` when the correct rear face and in-plane orientation are used. Physical R1 testing confirmed the official hole pattern but found that the coupon could not seat over the two retained raised hotend bosses. R2 preserves the pattern and adds pockets from user-measured Ø5 × 5 mm boss geometry. See `ENDER3_OFFICIAL_CARRIAGE_REAUDIT.md` and `ENDER3_OFFICIAL_CARRIAGE_COUPON_R2.md`. No adapter, selector transform, production EnderRack derivative, or tensioner redesign was generated.

## Decision summary

| Question | Result | Evidence / effect |
|---|---|---|
| Was the prior V2 work preserved? | PASS | 30 immutable copies are recorded in `archive/rejected-ender3v2-reference/archive_manifest.json`; originals remain in place. |
| Was official Ender-3 CAD used? | PASS | Exact repository commit and Git blob identities are recorded below. |
| Did the complete STEP import through FreeCAD MCP? | PASS | 1,243 objects; 1,178 shape-bearing objects; no null shapes, invalid topology, or invalid placements. |
| Did the FCStd survive save/close/reopen/recompute? | PASS | 1,243 objects and the embedded provenance record persisted. |
| Was the official X gantry isolated? | PASS | `EnderRack_Ender3_Official_Concept.FCStd` contains the `Ender3_X_Gantry_Official` group and 33 self-contained, valid shape copies. |
| Does the official plate match the real plate? | **PASS — visually provisional** | New photo evidence matches the rear/photo-oriented official `E plate` outline, three-wheel pattern, auxiliary holes, integral hotend bosses, and separate belt hardware. Physical dimensions are still gated by the coupon. |
| Did R1 correlate physically? | **CONDITIONAL PASS** | Hole pattern aligns; flat seating failed solely because the retained raised bosses lacked relief pockets. |
| Was an R2 printable coupon exported? | **PASS — digital** | Versioned FCStd, STEP, and STL retain R1 coordinates and add two physically dimensioned boss pockets. Physical R2 seating remains pending. |

## Rejected Ender-3 V2 work

Archive: `archive/rejected-ender3v2-reference/`

Status label: **REJECTED — WRONG MACHINE REFERENCE — ENDER-3 V2**

The archive contains 30 files, including the original community V2 STEP, V2 reference FCStd, V2-based concepts/designs, failed coupon FCStd/STEP/STL, screenshots, audits, and recovery records. `archive_manifest.json` records each source path, archived path, byte size, source timestamp, and SHA-256. The archived files are read-only copies; the originals were not deleted or modified.

New physical evidence is preserved as `interface-recovery/evidence/physical_plate_rear_2026-08-31.jpg`, SHA-256 `AA6078E69A8E5B0F2A0D393312A3B4198EC32DB7804CC294B9D424CF7C9D427F`.

## Official source provenance

Repository: [Creality3DPrinting/Ender-3](https://github.com/Creality3DPrinting/Ender-3)

Repository commit: `88c7758cea9d0d00a54fdb238bedb3b33425f409`

| Source | Repository path / identity | Bytes | SHA-256 | Local status |
|---|---|---:|---|---|
| `Ender3.STEP` | [`Ender-3 Mechanical/STP/Ender3.STEP`](https://github.com/Creality3DPrinting/Ender-3/blob/88c7758cea9d0d00a54fdb238bedb3b33425f409/Ender-3%20Mechanical/STP/Ender3.STEP); Git blob `30c9b930c0cc094b4d02acd72d71d835d7225c72` | 29,867,304 | `7E868F30A44F0E6B1DD0DAF8AF1D7810AD9A754CC6FA066F6EF4D2B81E3297AF` | Immutable/read-only |
| `Ender 3.f3d` | [`Ender-3 Mechanical/F360/Ender 3.f3d`](https://github.com/Creality3DPrinting/Ender-3/blob/88c7758cea9d0d00a54fdb238bedb3b33425f409/Ender-3%20Mechanical/F360/Ender%203.f3d); Git blob `998bd68bf940c3bd691fa9d7ead705bfa401e323` | 6,344,736 | `95909A53CCFAC0E4F3EFEC9B964780D5602B453F441274DFEBB4B5D18C2BC726` | Recorded and immutable/read-only; not imported |

Retrieved: `2026-08-31T18:06:44-06:00` (America/Denver).

Local source directory: `work/sources/ender-rack/official-ender3/`

The prior community Ender-3 V2 model was not used as a fallback.

## FreeCAD MCP import and digital validation

Deliverable: `Ender3_Official_reference.FCStd`

| Check | Result |
|---|---|
| MCP/RPC transport | PASS — listener verified at `127.0.0.1:9875`; no remote/wildcard binding |
| Imported document objects | 1,243 |
| Shape-bearing objects | 1,178 |
| Null geometry | 0 |
| Invalid topology | 0 |
| Invalid placements | 0 |
| Save/close/reopen/recompute | PASS |
| Reopened object count | 1,243 |
| Embedded source provenance | PASS |
| Obvious incomplete assembly | Not observed; frame, axes, belts, motors, endstops, bed, electronics, and hotend/fan assembly are present |

Intentional construction axes and origins were accepted. Their mathematically infinite bounding boxes were excluded from physical size calculations; they are not geometry failures.

Inventory: `../../work/ender-rack-inventory/ender3_official_import.json`

FCStd SHA-256: `56668B32302299CBFA9208167C4F50BA45C22BB1780F3A8E5E185FEA3840C75B`

## Official X carriage audit

The official assembly labels the sole carriage-plate candidate `E plate` (`Part__Feature286`). It is adjacent to the three X-stage V-wheels, X extrusion, X belt, hotend/fan assembly, belt clamps, motor, and endstop.

Measured directly from the imported BRep:

| Feature | Official CAD value |
|---|---:|
| Overall `E plate` bounding box | 64.000 × 63.949 × 27.400 mm |
| Plate base thickness between principal parallel faces | 2.500 mm |
| Upper wheel-axis center distance | 40.000 mm |
| Upper wheel line to lower/eccentric axis | 40.200 mm |
| Upper wheel through-hole diameter | 5.000 mm |
| Lower/eccentric through-hole diameter | 7.200 mm |
| Shape validity | PASS |

The official front view is [Ender3_Official_E_Plate_Face.png](screenshots/Ender3_Official_E_Plate_Face.png). The isolated stage is [Ender3_X_Gantry_Official.png](screenshots/Ender3_X_Gantry_Official.png).

### Physical correspondence gate — re-audited

New photographic evidence shows the physical carriage in the same orientation as the official rear view. The earlier rejection compared opposite faces and incorrectly required separate assembly hardware to be part of the bare plate solid.

- `Copper cover002/003` are separate gold belt-end/crimp objects visible above the rear plate face.
- The two 14 mm-spaced hotend bosses are integral counterbored/embossed topology in `E plate`.
- `M3X16 Pan Head Screw003/004` are separate hotend/radiator fasteners in `Sprinkler_assembly` and align with those bosses.
- Outline, three-wheel pattern, auxiliary holes, and hardware locations visually correspond.

The official plate therefore passes the visual gate and is promoted to **physical fit-check candidate**, not production reference. The photograph is perspective evidence; the printed coupon remains the dimensional gate. See [the front/rear comparison](screenshots/Ender3_Official_Carriage_FRONT-left_REAR-right.png) and `ENDER3_OFFICIAL_CARRIAGE_REAUDIT.md`.

## Official X-gantry working concept

Deliverable: `EnderRack_Ender3_Official_Concept.FCStd`

The `Ender3_X_Gantry_Official` group contains self-contained copies divided into:

- `Carriage_Plate_and_Wheels`
- `X_Extrusion_and_Belt`
- `X_Motor_and_Endstop`
- `X_Idler_and_Adjuster`

All 33 copied shape objects reopened validly and contain source-object metadata. The concept is labeled as official-reference geometry requiring physical verification; it is not a production EnderRack design.

Concept FCStd SHA-256: `55AEBD08090A8AA736FAB293295D40DA848D3648BA6094E3BDDE4B71E6C3302A`

## Coupon and production release status

R1 (`Ender3_Official_Carriage_FitCheck.FCStd`, STEP, and STL) remains preserved as the physical hole-correlation/boss-interference artifact. Its hole pattern passed, but the 2.0 mm plate could not seat over the retained bosses.

R2 (`Ender3_Official_Carriage_FitCheck_R2.FCStd`, STEP, and STL) keeps the 56.5 × 32.9 mm outline, four source-derived holes, wheel reliefs, V-notch, and cross. It adds two Ø5.5 × 5.2 mm-deep pockets based on the user's Ø5 × 5 mm physical boss measurements, leaves a 1.2 mm floor, and increases total thickness to 6.4 mm. It reopened as one valid solid; STEP and STL fidelity checks passed. Physical R2 seating remains the release gate.

No `EnderRack_15Lane_Ender3.FCStd` was created. No production adapter or production tensioner fabrication is authorized.

Print only R2 in PLA for fit-check use. PASS promotes the official plate to the EnderRack carriage reference. If it fails, document the exact interference and remeasure the controlling feature before changing geometry. A measured replacement carriage reference is not justified unless the corrected official interface still fails:

- `Y=0`: real outward steel mounting face;
- `X`: line through the two upper wheel axes;
- origin: motor-side upper wheel axis;
- `+X`: toward the tensioner;
- in-plane scan calibration: independent X and Z bars/cross;
- hole spacing: pin/bolt/drill-shank center-distance measurements where possible;
- depth and raised features: calipers/depth measurements, never inferred from the scan.

## Preserved conclusions and measurements

These remain valid or provisional independently of the rejected V2 carriage interface:

| Item | Status |
|---|---|
| Official TradRack R1 reference and selector geometry | Preserved |
| 17 mm lane pitch | Preserved; high confidence |
| 15-lane target / 238 mm first-to-last span | Preserved |
| 12-lane fallback / 187 mm first-to-last span | Preserved |
| Approx. 270 mm physical X-carriage travel / 135 mm midpoint | Preserved, provisional, medium-high confidence |
| Approx. 45 mm tensioner length | Preserved, provisional, low confidence |
| Approx. 7 mm tensioner protrusion | Preserved, provisional, low confidence; datum must be restated |
| Approx. 10 mm belt center on 20 mm extrusion | Preserved, provisional, low confidence; datum must be restated |
| Approx. 10 mm pulley center from extrusion end | Preserved, provisional, low-medium confidence |
| 15/12-lane parametric architecture | Preserved |
| Happy Hare/Klipper and electronics concept | Preserved; controller identity still unknown |

The detailed per-value provenance and datum notes remain in `interface-recovery/retained_physical_evidence.csv` and `interface-recovery/Physical_Interface_Parameters.csv`.

## Conclusions that must be recomputed

After the official-CAD coupon passes physical validation, recompute:

- carriage-to-selector rigid transform;
- adapter geometry and stand-off;
- mounting-hole use and fastener access;
- belt and belt-clamp clearance;
- cable routing;
- stock tensioner collision;
- endstop interaction;
- first/middle/last lane collision envelope;
- selector-position repeatability on the V-wheel stage.

All V2-derived selector offsets, hole coordinates, interface clearances, and tensioner collision conclusions remain rejected.

## Machine identity / upgrade audit

- **Mechanical identity:** Ender-3-family donor; official `E plate` visually correlated, physical coupon confirmation pending.
- **Display:** apparently non-original or later-style; not used for mechanical identification.
- **Controller board:** unknown until physically inspected.
- **Other upgrades:** unknown unless physically observed.

Electronics appearance did not affect the mechanical-source selection.

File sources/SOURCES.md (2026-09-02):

# EnderRack source and artifact provenance

Complete upstream CAD archives and assemblies are intentionally not committed. Paths below identify the local packaging machine; upstream URL, commit/blob, filename, byte size, and SHA-256 make the sources reproducible.

## Upstream sources

| Source | Identity | Local file | Bytes | SHA-256 | Role |
|---|---|---|---:|---|---|
| Creality Ender-3 official mechanical CAD | Repository `https://github.com/Creality3DPrinting/Ender-3`; commit `88c7758cea9d0d00a54fdb238bedb3b33425f409`; path `Ender-3 Mechanical/STP/Ender3.STEP`; blob `30c9b930c0cc094b4d02acd72d71d835d7225c72` | `work/sources/ender-rack/official-ender3/Ender3.STEP` | 29,867,304 | `7E868F30A44F0E6B1DD0DAF8AF1D7810AD9A754CC6FA066F6EF4D2B81E3297AF` | Correct donor assembly and E-plate reference |
| Creality Ender-3 Fusion source | Same repository/commit; path `Ender-3 Mechanical/F360/Ender 3.f3d`; blob `998bd68bf940c3bd691fa9d7ead705bfa401e323` | `work/sources/ender-rack/official-ender3/Ender 3.f3d` | 6,344,736 | `95909A53CCFAC0E4F3EFEC9B964780D5602B453F441274DFEBB4B5D18C2BC726` | Provenance reference; not imported for controlling geometry |
| TradRack R1 STEP archive | Repository `https://github.com/Annex-Engineering/TradRack`; commit `f89dc0b115adfc49195d782c5d7ecd348a574891`; path `CAD/Trad_Rack_R1_2024-03-04_STEP.7z`; blob `c1dbef9f292f7f7a3bec446b092be2f23ef4702f` | `work/sources/ender-rack/Trad_Rack_R1_2024-03-04_STEP.7z` | 91,473,657 | `BE7646216D6483DA49B548B7225BF3A64F07A12960D89EE659F0D2CCB5F271E8` | Stock selector and lane reference |
| TradRack extracted default STEP | Extracted from the pinned R1 archive | `work/sources/ender-rack/TradRack_STEP_extracted/trad_rack_(default).STEP` | 116,600,287 | `19459C5098A6C084D50F77AB4FBDBFABAB48D6845C84B3E9159F50776083BDB3` | Imported reference assembly |
| Community Ender-3 V2 STEP | Community source recorded in historical audit | `work/sources/ender-rack/Creality-Ender3-V2-rev4.STEP` | 36,580,869 | `D81BDE4587B3237FDA23515AD524482A8F0D153226B952A3B3734CBC29D3B5D0` | **Rejected wrong-machine reference; provenance only** |

## Tracked artifact dependencies

| Tracked artifact | Upstream dependency | Classification | Validation scope |
|---|---|---|---|
| `cad/fit-checks/Ender3_Official_Carriage_FitCheck_R2.FCStd` and matching exports | Official Creality E-plate hole pattern, seating face, orientation, and boss relationship | Reference-derived project fit coupon | Physical PASS only for exercised carriage-interface features |
| `cad/working/EnderRack_Selector_Interface_Coupon_R5.FCStd` and matching exports | R2-validated Creality interface plus TradRack selector/MGN mounting pattern and selector envelope | Substantially project-designed, upstream-interface-derived coupon | Digital PASS; real-selector physical test pending |
| Technical renders and verification records | Corresponding R2/R5 artifacts | Evidence | Do not treat images as dimensional authority |

Reference FCStd files that embed complete upstream assemblies remain local-only and are listed in [HASHES.md](HASHES.md).

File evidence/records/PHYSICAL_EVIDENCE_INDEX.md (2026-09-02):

# Physical evidence index

Personal physical-test photographs are deliberately excluded from Git history.

## R2 carriage coupon

Written result: **PHYSICAL FIT-CHECK PASS - 2026-09-01**.

The coupon seated on the real E plate, its validated holes aligned, and both raised bosses entered the clearance pockets. The physical photograph remains local at `validated/ender3-carriage-interface-r2-pass/physical-r2-pass-2026-09-01.jpg` and has SHA-256 `D78D12F9B7EA80A55DE253FE2A55C139E67D28A2B6061801CB97E51122704DC6`.

## R5 selector coupon

Physical test: **PENDING**.

R5 must be re-sliced with a verified original Ender-3-family profile and approved PLA temperature before printing. No R5 physical PASS photo or result exists yet.

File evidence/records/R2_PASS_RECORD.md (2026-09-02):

# Official Ender-3 carriage interface R2 — physical PASS

Status: **PHYSICAL FIT-CHECK PASS — 2026-09-01**

The photographed R2 coupon seated on the real Ender carriage plate with its validated hole pattern aligned and its two boss-clearance pockets accepting the retained raised hotend features. This promotes the official E plate only as the controlling fabricated-fit reference for the physically exercised interface features:

- hole-pattern position and orientation;
- steel seating face;
- R2 V-notch = tensioner/idler side;
- R2 cross = motor side;
- boss-clearance relationship used by R2.

It does not physically validate every official E-plate contour, the belt datum, wheel stack depth, or any unencountered feature. The bosses remain clearance features, not precision locating datums. Location is controlled by the validated fastener pattern and steel contact face.

The successful relief geometry is **two pockets, diameter 5.5 mm × 5.2 mm deep**. The 5 × 5 mm values used to derive those pockets are nominal successful coupon inputs, not independently measured boss dimensions.

## Preserved artifacts

| File | Bytes | SHA-256 |
|---|---:|---|
| `Ender3_Official_Carriage_FitCheck_R2.FCStd` | 27,839 | `5BFCCEA429CA99938D7D4C6E331EAB8527BCAC78F001BD873B6BBEB9D56F6B39` |
| `Ender3_Official_Carriage_FitCheck_R2.step` | 43,823 | `CEB0FF7112BBFD7E4EDBA46C828C431A68E6472DCBF275925C5A48B8941B4AFC` |
| `Ender3_Official_Carriage_FitCheck_R2.stl` | 46,284 | `E57E049BD18FC0F773B481B130ADC6976BBFF6C08E0909EE653916B485F3D88B` |
| `physical-r2-pass-2026-09-01.jpg` | 90,001 | `D78D12F9B7EA80A55DE253FE2A55C139E67D28A2B6061801CB97E51122704DC6` |

These are exact archive copies of the successful digital coupon and the received PASS photograph. They must not be silently regenerated or replaced.

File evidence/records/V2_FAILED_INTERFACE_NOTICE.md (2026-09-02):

# EnderRack Carriage Interface Invalidation Notice

**PHYSICAL FIT-CHECK FAIL — COMMUNITY CARRIAGE INTERFACE REJECTED**

Do not fabricate or continue production adapter, tensioner, belt-clamp, or endstop work from the carriage interface contained in:

- `../EnderRack_15Lane_Design.FCStd`
- `../EnderRack_Interface_FitCheck.FCStd`
- `../exports/EnderRack_Interface_FitCheck.step`
- `../exports/EnderRack_Interface_FitCheck.stl`

These files are preserved as forensic evidence and as a source for the unaffected TradRack and parametric lane work. They must not be treated as a verified Ender-3 V2 carriage interface.

The digital audit proved that the E1–E5 centers passed through the adapter, FCStd, STEP, and STL without a meaningful transform/export error. It also found that the selected community-CAD cylinders were not all equivalent mounting holes, although the coupon converted every center to a Ø3.40 mm clearance hole. The user’s physical fit-check established that the resulting pattern does not match the plate on this machine.

Resume interface design only after a measured carriage reference passes the paper template and primary PLA plate coupon defined in `PHYSICAL_MEASUREMENT_WORKSHEET.md`.

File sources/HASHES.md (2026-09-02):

# EnderRack hash manifest

Hashes were recomputed during repository packaging on 2026-09-01. Historical report hashes for mutable FreeCAD documents may differ after later saves or view-state updates; the values below are the packaging-time identities.

## Canonical tracked artifacts

| Artifact | Bytes | SHA-256 |
|---|---:|---|
| `cad/fit-checks/Ender3_Official_Carriage_FitCheck_R2.FCStd` | 27,839 | `5BFCCEA429CA99938D7D4C6E331EAB8527BCAC78F001BD873B6BBEB9D56F6B39` |
| `exports/fit-checks/Ender3_Official_Carriage_FitCheck_R2.step` | 43,823 | `CEB0FF7112BBFD7E4EDBA46C828C431A68E6472DCBF275925C5A48B8941B4AFC` |
| `exports/fit-checks/Ender3_Official_Carriage_FitCheck_R2.stl` | 46,284 | `E57E049BD18FC0F773B481B130ADC6976BBFF6C08E0909EE653916B485F3D88B` |
| `cad/working/EnderRack_Selector_Interface_Coupon_R5.FCStd` | 17,536,897 | `B1EFD105F3B6D260C9538530F6B6DCBD37D0BAF2DC2C60AE2D66472AFE44FA49` |
| `exports/fit-checks/EnderRack_Selector_Interface_Coupon_R5.step` | 79,900 | `A471DE9772790A6DEC882545069C8CBD4F0CE840D9EA4DB57C37403A67E531C4` |
| `exports/fit-checks/EnderRack_Selector_Interface_Coupon_R5.stl` | 76,084 | `6070C29687531215B4A7D58FBD1C77B53CB3CB9BBB349A0F10DA72946EF2EBAC` |

## Local-only source/reference files

| File | Bytes | SHA-256 |
|---|---:|---|
| Official `Ender3.STEP` | 29,867,304 | `7E868F30A44F0E6B1DD0DAF8AF1D7810AD9A754CC6FA066F6EF4D2B81E3297AF` |
| Official `Ender 3.f3d` | 6,344,736 | `95909A53CCFAC0E4F3EFEC9B964780D5602B453F441274DFEBB4B5D18C2BC726` |
| TradRack R1 STEP archive | 91,473,657 | `BE7646216D6483DA49B548B7225BF3A64F07A12960D89EE659F0D2CCB5F271E8` |
| Extracted TradRack default STEP | 116,600,287 | `19459C5098A6C084D50F77AB4FBDBFABAB48D6845C84B3E9159F50776083BDB3` |
| Rejected community V2 STEP | 36,580,869 | `D81BDE4587B3237FDA23515AD524482A8F0D153226B952A3B3734CBC29D3B5D0` |
| `TradRack_R1_reference.FCStd` | 62,615,614 | `44C648541BDC0765A3A2DF6FE73B9109B4C2D1AC811FF7B2D16B4281FB0089CF` |
| `Ender3_Official_reference.FCStd` | 17,675,431 | `19CF1CE1305ED84824DB96470581DBEF0966C70EEAD9AE09A5C69FA1D4A39EE1` |
| `EnderRack_Ender3_Official_Concept.FCStd` | 513,727 | `A73E6959B8B88FF281AF5AF15B86CB9A453EEDD8A15525E484559B964908477C` |

The R2 physical photograph remains local and untracked. Its recorded SHA-256 is `D78D12F9B7EA80A55DE253FE2A55C139E67D28A2B6061801CB97E51122704DC6`.

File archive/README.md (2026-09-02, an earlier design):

# EnderRack archive index

Archived and superseded binary work remains on the packaging machine but is intentionally not committed.

## Rejected V2 reference

Local archive: `archive/rejected-ender3v2-reference/`

Status: **REJECTED - WRONG MACHINE REFERENCE - ENDER-3 V2**

This archive contains the community V2 STEP, V2 reference and concept FCStd files, failed interface work, screenshots, audits, and an archive manifest. Its file hashes remain evidence, but its fabricated-fit geometry is not reusable for the original/older Ender-3 donor.

## Superseded interface revisions

R1/R2 established the official E-plate interface. R3 and R4 were development revisions of the secondary selector coupon. R5 supersedes them because it corrects the exact weak lateral wheel-edge ligament while retaining the intended gussets.

## Legacy reports

Historical reports are copied under `docs/reports/legacy/`. They retain useful feasibility and lane-system evidence but contain rejected V2-derived carriage transforms and collision conclusions. Read `docs/CURRENT_STATE.md` before consulting them.

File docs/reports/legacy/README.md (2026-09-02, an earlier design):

# Legacy report warning

The reports in this directory predate the donor-source correction. They contain useful TradRack, lane-pitch, physical-travel, and parametric-architecture work, but their Ender-3 V2 carriage coordinates, transforms, adapter geometry, and collision conclusions are rejected.

Do not fabricate from these reports. Current authority is `docs/CURRENT_STATE.md` followed by `docs/ENDER_RACK_HANDOFF.md`.

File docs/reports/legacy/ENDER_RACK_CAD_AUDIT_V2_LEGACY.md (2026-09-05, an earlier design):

> Historical evidence only. Not the current design or print instruction. R5 relationships and 22.25 mm stand-off are retired; see docs/CURRENT_STATE.md.

# EnderRack Mechanical Feasibility Audit

> **LEGACY / SUPERSEDED:** This report uses the rejected Ender-3 V2 carriage reference. Preserve its TradRack and lane-analysis evidence only. Do not use its carriage coordinates, transforms, adapter geometry, or collision conclusions for fabrication.

> **2026-08-31 PHYSICAL INTERFACE CORRECTION:** The printed carriage coupon did not match the plate on this machine. The subsequent forensic audit proved that the digital E1–E5 center pipeline was faithful but that the community carriage interface is incompatible with the physical specimen and its source features were oversimplified. All carriage-interface-dependent transforms and collisions are superseded. Independent physical travel/tensioner evidence and official TradRack geometry remain valid at their recorded confidence. See [`interface-recovery/ENDER_CARRIAGE_INTERFACE_AUDIT.md`](interface-recovery/ENDER_CARRIAGE_INTERFACE_AUDIT.md).

## 2026-08-31 design-phase rebaseline

This section supersedes the earlier lane recommendation and interface-overlap conclusions below. The original feasibility record remains intact for traceability. Detailed implementation and verification results are in `ENDER_RACK_DESIGN_REPORT.md`.

**Release state: PROVISIONAL — FIT-CHECK FABRICATION ONLY. DO NOT FABRICATE PRODUCTION PARTS.**

| Question | Updated result | Design-phase conclusion |
|---|---|---|
| Can the Ender X stage replace MGN9? | **CONDITIONAL YES** | The parametric conversion is viable at center and the interface adapter is a valid single solid. Production use is gated by a left-end selector/tensioner interference, physical travel/endstop measurements, and repeatability testing. |
| Can the stock selector remain essentially unchanged? | **CONDITIONAL** | The drive, servo, filament path, lane modules, and main selector structure remain stock. Two interface fasteners and the stock cable-chain anchor require replacement. The lower selector motor mount conflicts with the stock Ender tensioner at left-side lane positions; resolve with a measured low-profile tensioner or a separately approved larger stand-off. |
| What transform is implemented? | **PROVISIONAL** | `T_EnderCarriage_From_TradRackSelector = [X 0.000, Y +13.5529, Z -9.3850 mm; roll/pitch/yaw 0°]`. This is the reference alignment plus a controlled +8.250 mm outward adjustment. |
| How many lanes are targeted? | **15 TARGET / 12 FALLBACK / 16 NOT RELEASED** | At 17 mm pitch: 15 requires 238 mm and leaves 32 mm gross within the rough 270 mm observation; 12 requires 187 mm; 16 requires 255 mm and leaves only 15 mm gross. The exact left-end packaging conflict affects both the centered 15- and 12-lane visualizations, so neither is production-cleared yet. |
| What must be verified next? | **PHYSICAL GATES REMAIN** | Accurate switch-click-to-safe-opposite travel, asymmetric end reserves, carriage holes/face, belt and tensioner geometry, selector mass, harness routing, and first/middle/last-lane repeatability. |

The 270 mm center-hole observation is useful but remains a rough physical measurement. `ArrayOffset` therefore remains editable and centered only for visualization; it must eventually maximize the smaller verified end clearance rather than enforce symmetry.

The design document adds a parametric 15/12/16 lane array, a relieved carriage adapter, removable trigger concept, service-clearance volumes, and a fit-check-only derivative. Exact BRep checks found zero center-position collision after excluding components explicitly classified for replacement. At the centered 15-lane first extreme, the stock lower selector motor mount intersects the stock Ender tensioner housing, and moving the selector farther outward by approximately 15 mm beyond the implemented offset was required to clear it in a probe. That larger change was not adopted because it exceeds the approved small controlled optimization and would require new module-mounting provisions.

15-lane design

Parametric adapter interface

Fit-check derivative

Generated 2026-08-30 with FreeCAD 1.1.3 and FreeCAD MCP 0.1.22. All CAD imports, isolation, measurements, collision checks, document saves, reopening, and screenshots were performed through the local FreeCAD MCP connection on `127.0.0.1:9875`.

## Executive conclusion

| Question | Result | Mechanical conclusion |
|---|---|---|
| Can the complete Ender X linear stage replace the MGN9 stage? | **CONDITIONAL YES** | The modeled Ender stage provides 251.742 mm of collision-limited CAD travel and carries the selector through the tested lane positions. The community Ender model does not provide a trustworthy belt strand, wiring envelope, or usable endstop/homing range, so real-machine validation is mandatory. |
| Can the stock TradRack selector remain essentially unchanged? | **CONDITIONAL** | The drive core, motor, servo, filament path, sensor, and lane modules can remain stock. The MGN9 rail/carriage are removed. At the extrusion-aligned interface, two printed carriage pieces and two fasteners intersect the Ender plate; local relief/stand-off and fastener substitution are required. |
| What interface transformation is required? | **PROVISIONAL REFERENCE** | In the normalized Ender carriage frame: **X 0.000 mm, Y +5.303 mm, Z −9.385 mm; roll/pitch/yaw 0°**. This aligns the two 20×20 extrusion centerlines and parallel travel axes. It preserves stock lane geometry but leaves 64.723 mm³ of localized interface overlap to resolve during adapter design. |
| How many lanes fit? | **8 PASS / 12 PASS / 15 CAD-MAX** | Module mounting length supports 19 positions; modeled selector travel is the first constraint at 15. Twelve lanes is the provisional physical-verification-gated recommendation. |
| What must be measured physically? | **SEE PRIORITY LIST** | Carriage holes/face, wheel geometry, extrusion, belt, endstop/homing range, and plate-to-V-slot datums are the gating measurements. |

This phase does **not** establish production readiness or dynamic load capacity. It establishes that the geometry is promising and identifies the exact uncertainties the next phase must close.

## Source provenance and import status

### TradRack

- Source repository: <https://github.com/Annex-Engineering/TradRack>
- Repository `main` commit at download: `f89dc0b115adfc49195d782c5d7ecd348a574891`
- Git blob: `c1dbef9f292f7f7a3bec446b092be2f23ef4702f`
- Archive: `Trad_Rack_R1_2024-03-04_STEP.7z`
- Archive size: 91,473,657 bytes
- Archive SHA-256: `BE7646216D6483DA49B548B7225BF3A64F07A12960D89EE659F0D2CCB5F271E8`
- Imported baseline: `trad_rack_(default).STEP`
- STEP size: 116,600,287 bytes
- STEP SHA-256: `19459C5098A6C084D50F77AB4FBDBFABAB48D6845C84B3E9159F50776083BDB3`
- Import: **PASS**, 1,812 FreeCAD objects. No null imported shapes and no invalid topology found in the full validation pass.

The archive also contains official 6 mm belt, 9 g servo, NEMA 14, and breakout-board variants. They were recorded but not mixed into the default baseline.

### Ender-3 V2

- Preferred Printables page: <https://www.printables.com/model/255019-ender-3-v2-step-file-for-easy-modification-and-design>
- Preferred-page automation result: HTTP 403, so the supplied mirror was used.
- Mirror: <https://www.dropbox.com/s/cl4yxvw00t8knvq/Creality-Ender3-V2-rev4.STEP?dl=1>
- File: `Creality-Ender3-V2-rev4.STEP`
- Size: 36,580,869 bytes
- SHA-256 provenance record: `D81BDE4587B3237FDA23515AD524482A8F0D153226B952A3B3734CBC29D3B5D0`
- Import: **PASS**, 537 FreeCAD objects. No null Part features; targeted X-gantry, plate, and wheel topology checks passed.

The Ender file is community CAD, not authoritative Creality mechanical CAD. Its hash records what was analyzed; it does not certify dimensional accuracy.

## Coordinate systems and interface

The concept uses a right-handed Ender carriage frame:

- **+X:** carriage travel along the X extrusion
- **+Y:** outward from the Ender carriage mounting face toward the TradRack selector
- **+Z:** physical up
- **Origin:** centroid of the selected carriage-interface cylindrical features, projected onto the outward plate face

The TradRack selector frame is centered on the outward face of the MGN9 carriage with +X along the stock rail. The reference transform was obtained by aligning the stock TradRack and Ender 20×20 extrusion centerlines while keeping their travel axes parallel.

| Component | X | Y | Z / other |
|---|---:|---:|---:|
| Provisional TradRack-frame translation | 0.000 mm | +5.303 mm | −9.385 mm |
| Rotation | 0° roll | 0° pitch | 0° yaw |
| MGN9 carriage mounting pattern | 10.000 mm | 15.000 mm | Four nominal Ø3 mm axes |
| Ender plate thickness | — | 2.500 mm | Parallel major-face separation |
| Inferred Ender belt centerline | — | −15.256 mm | Z −9.397 mm |

The continuous Ender belt strand is absent from the community STEP. Its centerline is inferred from the motor pulley and two idler-bearing centers and must be checked physically.

### Interface interference

The extrusion-aligned transform has 64.723 mm³ of exact BRep intersection:

| Ender component | TradRack component | Intersection |
|---|---|---:|
| Metal hotend carriage plate | Carriage Middle, 9 mm belt C-cart | 5.321 mm³ |
| Metal hotend carriage plate | Carriage Left | 1.536 mm³ |
| Metal hotend carriage plate / one V-wheel | M5×10 socket-head fastener | 43.259 mm³ total |
| Metal hotend carriage plate | M3×8 socket-head fastener | 14.607 mm³ |

Moving the complete TradRack reference outward by up to 10 mm did not produce a clean no-intersection state, because stock carriage geometry extends behind its MGN interface plane. A simple rigid stand-off therefore does not make the assembly drop-in while preserving the stock lane/extrusion relationship. The adapter phase must provide local relief and replace/reorient the two interfering fasteners; the two printed carriage parts may need local revision if relief cannot be contained in the adapter.

Interface close-up

## Ender carriage measurements

### Wheel and plate geometry

Wheel centers in the Ender carriage frame:

| Wheel | X | Z |
|---|---:|---:|
| Upper/first wheel (`Part__Feature192`) | +33.300 mm | +11.878 mm |
| Eccentric/lower wheel (`Part__Feature193`) | +13.300 mm | −28.122 mm |
| Upper/third wheel (`Part__Feature194`) | −6.700 mm | +11.878 mm |

Center distances are 40.000 mm between the two aligned wheels and 44.721 mm from each aligned wheel to the eccentric wheel. The modeled eccentric spacer center is approximately X +13.946 mm, Z −27.453 mm. These are high-priority caliper checks.

The plate contains several cylindrical holes, counterbores, and bosses. Their complete measured coordinates and diameters are stored in `Dimensional_Audit`; they must not all be assumed to be available adapter fasteners until the physical plate is checked. The most relevant non-wheel candidate axes include nominal Ø3.00, Ø3.02, Ø4.00, and concentric Ø5.27 features.

### Donor-stage envelope

- Ender X extrusion: **345.000 × 20.000 × 20.000 mm**
- Donor carriage/plate/wheel envelope: approximately **37.740 × 64.080 × 64.080 mm** in imported world-envelope order
- Ender X belt strand: **not modeled**
- Wiring/harness flex envelope: **not modeled**

Isolated Ender donor

## Travel and lane capacity

### Travel

| Quantity | Result | Meaning |
|---|---:|---|
| Wheel-on-extrusion geometric delta range | −169.150 to +111.773 mm | Wheel centers remain on modeled extrusion |
| Raw CAD travel | **252.242 mm** | Wheel-track limit plus exact fixed-end collision checks |
| Usable modeled selector travel | **251.742 mm** | Combined donor + selector, 0.25 mm inside each modeled limit |
| First-end clearance at usable limit | 0.023 mm | Essentially a CAD contact limit, not a production clearance |
| Other-end clearance at usable limit | 2.006 mm | Modeled BRep clearance |

The modeled plate did not positively actuate the endstop lever before the wheel-track limit. Therefore the 251.742 mm value is **not a verified homed operating range**. Real endstop trigger, switch overtravel, belt clamp, and homing overshoot will reduce it.

### Independent capacity constraints

- Measured TradRack lane pitch: **17.000 mm**
- Transformed lane-module X envelope: **19.007 mm**
- Collision-free module-center interval: **−161.385 to +146.615 mm**
- Module-mounting capacity: **19 lanes**
- Selector-travel capacity: **15 lanes**
- First limiting constraint: **selector travel**

| Lane count | First-to-last center travel | Extreme collision check | Result |
|---:|---:|---|---|
| 8 | 119.000 mm | Both extremes clear | **PASS** |
| 12 | 187.000 mm | Both extremes clear | **PASS** |
| 15 | 238.000 mm | Both extremes clear in community CAD | **CAD PASS / PHYSICALLY UNVERIFIED** |

Removing 5 mm from both modeled travel ends still produces a pitch calculation of 15 lanes, but only about 3.7 mm of total pitch headroom remains beyond the 238 mm requirement. Because the modeled endstop result is unusable and one extreme is nearly in contact, **12 lanes is the provisional recommendation** until real usable travel is measured. Fifteen is the geometric maximum, not a build recommendation.

First modeled selector extreme

Last modeled selector extreme

## TradRack change classification

### Unchanged

- Filament drive core and NEMA17 drive motor
- Servo and servo mechanism
- Filament sensor and ECAS/output path geometry
- Lane-module bodies, bearings, and 17 mm pitch
- Most selector printed structure and hardware
- End modules, subject to the Ender end-hardware collision check

### Repositioned only

- Lane-module bank onto the Ender 20×20 reference extrusion
- Selector belt system and end attachments
- Cable chain or replacement harness routing; the imported chain is not a valid rigid-motion collision envelope

### Replacement or local revision required

- New Ender-carriage-to-selector adapter
- M5×10 and M3×8 fasteners that intersect the Ender plate
- Local clearance for `Carriage Middle` and `Carriage Left`; revise those pieces only if the adapter cannot provide the relief

### Possibly unnecessary

- MGN9 rail and carriage
- Stock TradRack 280 mm extrusion, because its 20×20 centerline was mapped onto the Ender extrusion
- MGN9 rail stop
- Original K3 mounting brackets

Isolated TradRack selector reference

Combined concept

## Load/footprint comparison

No credible material-density metadata was present, so mass and inertia were not invented.

| Assembly | BRep envelope | Modeled solid volume |
|---|---|---:|
| TradRack moving selector, excluding MGN9 and rigid cable-chain treatment | 112.100 × 89.064 × 111.100 mm | 160,727.9 mm³ |
| Removed Ender hotend/fan assembly | 54.024 × 67.791 × 67.791 mm | 52,672.1 mm³ |

The selector is roughly three times the modeled solid volume and has a substantially larger envelope. Volume is not mass, and the TradRack axis will move more slowly than a print hotend, but the CAD does **not** support an assumption that the moving load is equivalent. Weigh the physical selector and calculate acceleration/belt loads before setting motion parameters.

## Physical verification priorities

1. Measure every proposed Ender carriage adapter hole: center coordinates, diameter, counterbore/boss, and usable thread/clearance.
2. Verify the outward carriage face plane, 2.5 mm plate thickness, bends, and local embossments.
3. Verify all three wheel centers, the 40.000/44.721 mm spacing, and eccentric range.
4. Measure the Ender extrusion section, actual cut length, and usable T-slot length between end hardware.
5. Measure the belt centerline, belt-clamp geometry, motor pulley, and idler/tensioner clearance.
6. Measure the actual X endstop trigger point, switch overtravel, homing overshoot, and hard-collision limits.
7. Measure real usable carriage travel with the factory belt and endstop installed; **187 mm is the minimum needed for 12 lanes and 238 mm for 15**.
8. Measure carriage-face-to-V-slot reference distances and wheel contact-plane offsets.
9. Check the TradRack selector entry/output centerline against the first and last physical lane positions.
10. Weigh the complete moving selector and removed Ender hotend/fan assembly; set conservative acceleration only after belt and wheel-load review.

## Deliverable verification

- All three FCStd files were closed, reopened, and recomputed through MCP: **PASS**.
- Required concept groups and `Dimensional_Audit`: **PASS**.
- Reopened object counts: TradRack 1,812; Ender 537; concept 623.
- No null Part features in the reopened documents; targeted interface topology checks passed.
- Existing unrelated FreeCAD documents `Unnamed` and `parametric_l_bracket` remained open and untouched.
- Source archive and STEP hashes remained unchanged after the complete workflow.
- Local RPC remained bound only to `127.0.0.1:9875`.

## File hashes

| Deliverable | SHA-256 |
|---|---|
| `TradRack_R1_reference.FCStd` | `893EC9FDA18AC8F12F0146C73DC632FA9542FCF0BAA3AD97D5BBE908028ED768` |
| `Ender3V2_reference.FCStd` | `894B6FE2D1A605C4C2FBEB6D8400565C818AC563AF3E84669EBAAFA5DE6BBB53` |
| `EnderRack_Concept.FCStd` | `96F41CBEDA633CB7D9129F39E6269E7895752B6C452B4DEE0E06F2B09E5858FD` |

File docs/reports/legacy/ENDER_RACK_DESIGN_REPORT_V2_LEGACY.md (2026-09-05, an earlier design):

> Historical evidence only. Not the current design or print instruction. R5 relationships and 22.25 mm stand-off are retired; see docs/CURRENT_STATE.md.

# EnderRack 15-Lane Conversion Design Report

> **LEGACY / SUPERSEDED:** R5 was the controlling article when this historical report was archived; it is now retired. This report is retained as engineering history and must not override `docs/CURRENT_STATE.md` or the current handoff.

> **SUPERSEDED CARRIAGE INTERFACE — PHYSICAL FIT-CHECK FAILED.** Do not fabricate the adapter or continue tensioner redesign from this document's community-CAD carriage coordinates. The digital pipeline reproduced the selected E1–E5 centers correctly, but the pattern does not match the plate on this machine and the selected source cylinders were not all equivalent mounting holes. Preserve the unaffected TradRack and lane-system work. See [`interface-recovery/ENDER_CARRIAGE_INTERFACE_AUDIT.md`](interface-recovery/ENDER_CARRIAGE_INTERFACE_AUDIT.md).

**Status: PROVISIONAL — FIT-CHECK FABRICATION ONLY. DO NOT FABRICATE PRODUCTION PARTS.**

Generated 2026-08-31 in FreeCAD 1.1.3 through the local FreeCAD MCP connection on `127.0.0.1:9875`.

## Outcome

The requested parametric conversion model is implemented. It has a 15-lane target, a 12-lane fallback generated from the same model, editable travel and array parameters, a relieved Ender-carriage adapter, a removable endstop-trigger concept, service-access envelopes, and a separate PLA fit-check derivative exported as STEP and STL.

The interface and parameter pipeline pass. The complete mechanism is **not production-cleared**: exact BRep checks expose a stock-selector/stock-Ender-tensioner conflict over the left-side travel region. This is the first production geometry item to resolve after physical measurement. The rough 270 mm observation supports a 15-lane target but does not prove usable homed travel.

| Item | Result |
|---|---|
| Parametric 15/12/16 lane regeneration | **PASS** |
| Close, reopen, and recompute | **PASS** |
| Adapter topology | **PASS — one valid solid** |
| Fit-check FCStd/STEP/STL | **PASS** |
| Center-position exact collision check | **PASS — zero collisions after declared replacement parts are excluded** |
| Centered 15-lane first extreme | **FAIL — lower selector motor mount vs Ender tensioner; one Ender moving screw also reaches fixed roller hardware at −119 mm** |
| Centered 15-lane last extreme | **PASS in community CAD** |
| Production exports | **NOT CREATED, by design** |
| Production mechanical release | **FAIL / gated by physical verification and left-end redesign** |

## Deliverables

- `EnderRack_15Lane_Design.FCStd` — self-contained parametric design document.
- `EnderRack_Interface_FitCheck.FCStd` — isolated fit-check assembly and manufacturing notes.
- `exports/EnderRack_Interface_FitCheck.step` — fit-check geometry only.
- `exports/EnderRack_Interface_FitCheck.stl` — fit-check geometry only, 960 facets.
- `ENDER_RACK_CAD_AUDIT.md` — original feasibility audit plus design-phase rebaseline.
- `screenshots/07-ender-rack-15-lane-design.png` through `11-interface-fitcheck-part.png` — implementation views.

No production STEP or STL was generated.

## Master parameters

The FreeCAD spreadsheet `Master_Parameters` drives the lane array, travel scenarios, interface placement, adapter thickness, service clearances, and print-fit allowances.

| Parameter | Current value | Role |
|---|---:|---|
| `ActiveLaneCount` | 15 | Change to 12 for fallback or 16 for sensitivity only |
| `LanePitch` | 17.000 mm | Measured stock TradRack pitch |
| `RequiredActiveTravel` | 238.000 mm | `(ActiveLaneCount - 1) × LanePitch` |
| `ProvisionalPhysicalTravel` | 270.000 mm | Rough user measurement; not a verified operating limit |
| `ArrayOffset` | 0.000 mm | Initial visualization only; keep editable until asymmetric end reserves are measured |
| `SelectorYAdjustment` | +8.250 mm | Controlled outward optimization from the audit reference transform |
| `SelectorZAdjustment` | 0.000 mm | Editable; currently preserves the reference filament relationship |
| `FinalTransformY` | +13.552904 mm | Reference Y + controlled adjustment |
| `FinalTransformZ` | −9.384951 mm | Reference Z |
| `AdapterThickness` | 7.726639 mm | Derived from measured mating planes and Y adjustment |
| `M3ClearanceDiameter` | 3.400 mm | Fit-check starting value for a 0.4 mm nozzle process |
| `PrintRadialClearance` | 0.200 mm | Fit-check compensation, to calibrate on the actual printer |

Changing `ActiveLaneCount` to 12 regenerates 12 lane instances at the same pitch. The verification run also exercised 16 lanes and changed travel to 268/272 mm and selector Y to +8.750 mm; derived travel, first/last centers, adapter thickness, and geometry updated and then returned to the 15-lane baseline.

## Lane scenarios

| Lanes | First-to-last centers | Gross remainder within rough 270 mm | Design status |
|---:|---:|---:|---|
| 12 | 187 mm | 83 mm | Fallback after the same left-end tensioner issue is resolved |
| 15 | 238 mm | 32 mm | Primary target; sensible but physically unverified |
| 16 | 255 mm | 15 mm | Sensitivity only; not released because endstop/hardware reserve is too small |
| 17 | 272 mm | −2 mm | Does not fit the rough measured center travel |

The stock lane/module mounting geometry measured in the audit can pack 19 positions. Travel and end packaging remain the limiting constraints. Final `ArrayOffset` must maximize the smaller of the measured switch-side and far-side safe clearances; centering is not a release assumption.

## Implemented interface

The implemented transform is:

`T_EnderCarriage_From_TradRackSelector = translation(0.000, +13.552904, −9.384951 mm) × rotation(0°, 0°, 0°)`

It retains parallel travel axes and parallel mating planes while moving the selector +8.250 mm outward from the original reference alignment. This places the official module mounting-hole Y datum within 0.250 mm of the measured Ender lower-slot centerline.

The adapter is an L-relieved, parametric one-piece fit-check solid:

- bounding box: **62.000 × 7.726639 × 36.000 mm**;
- exact BRep volume: **14,471.748 mm³**;
- five measured Ender plate hole checks;
- three usable stock selector M3 interface locations;
- three captive-nut pockets;
- localized NEMA motor and cable-cover reliefs;
- a 3.2 mm minimum structural back wall at the motor relief;
- service-access cylinders representing fastener approach, not invented tool models.

The lower-left stock selector fastener is intentionally unavailable inside the motor-relief zone. Two previously colliding selector fasteners are classified for replacement. Hole authority remains provisional until the physical Ender plate is measured.

Adapter interface

## Collision results and disposition

The exact checks used component BReps rather than only bounding-box estimates. Intentional visualization envelopes were excluded.

| Pose | Translation | Exact result |
|---|---:|---|
| Center | 0.0 mm | 0 collisions |
| 12-lane first, centered | −93.5 mm | Selector lower motor mount intersects Ender tensioner housing |
| 12-lane last, centered | +93.5 mm | 0 collisions |
| 15-lane first, centered | −119.0 mm | Selector lower motor mount intersects Ender tensioner; moving Ender M5 screw reaches fixed Z-roller plate |
| 15-lane last, centered | +119.0 mm | 0 collisions |
| 16-lane first, centered | −127.5 mm | Multiple end-hardware collisions |
| 16-lane last, centered | +127.5 mm | Adjustable trigger begins intersecting the gear enclosure |

Pose probes found that shifting the selector approximately 15 mm farther outward than the implemented +8.250 mm adjustment clears the selector/tensioner collision at a candidate 15-lane first position near −112.5 mm. That larger stand-off was deliberately **not** adopted: it is not the approved small optimization, it would increase the adapter and overturn the near-slot module mounting relationship, and it should be compared against a measured low-profile Ender tensioner solution first.

The current production-design branch therefore needs one of these evidence-backed resolutions:

1. measure and design a low-profile Ender X tensioner that preserves belt centerline and adjustment; or
2. authorize a larger selector stand-off plus explicit lane-module mounting brackets; or
3. reduce/reposition the operating lane window after accurate travel and obstruction measurements.

## Component change classification

### Unchanged

- TradRack filament drive core, NEMA motor, servo mechanism, filament sensor, and entry/output geometry;
- lane-module bodies, bearings, and 17 mm pitch;
- most selector printed structure and hardware;
- Ender X extrusion, V-wheel carriage, motor-side hardware, and belt path reference.

### Repositioned only

- complete selector reference and lane bank through the named parametric transform;
- lane array along X through `ArrayOffset` and `ActiveLaneCount`;
- endstop trigger position after physical switch measurement;
- wiring flex envelope after harness routing is known.

### Replacement required

- MGN9 rail and carriage, replaced by the Ender V-wheel stage and adapter;
- two selector interface fasteners identified in the feasibility audit;
- stock TradRack cable-chain anchor (`Part__Feature405`), because its mounting form intersects an Ender M5 wheel screw;
- a left-end packaging component: provisionally the Ender tensioner housing, unless a later authorized stand-off solution proves preferable.

### Possibly unnecessary

- stock TradRack 280 mm extrusion if the lane modules are mounted to the Ender extrusion or a shared replacement member;
- original MGN9 rail stop and K3 mounting brackets;
- rigid cable chain if a lighter verified flex harness is used.

## Fabrication guidance

The exported part is for **interface fit checking only**.

- Fit-check material: PLA, 0.4 mm nozzle.
- Production adapter baseline after release: PETG minimum; ABS/ASA acceptable.
- Do not use the current PLA fit-check part as a production motion component.
- Verify all five Ender hole locations, selector fastener access, captive-nut fit, plate-face seating, motor relief, and cable-cover relief before editing the production design.
- Do not drill or permanently modify the Ender carriage from these community-CAD coordinates.

## Physical and dynamic release gates

1. Measure from the same carriage center hole at **X switch just clicked** to the **furthest safe opposite position**, without forcing the carriage. Record the two endpoint coordinates separately; ±2 mm is sufficient for the current lane decision.
2. Measure the stock tensioner housing, adjustment knob, Ender moving screw/roller plate, belt centerline, and usable clearance around the proposed first lane.
3. Verify carriage adapter holes, plate face, thickness, bosses/counterbores, and accessible fastener approach.
4. Verify lane-module mounting datums and the selector filament centerline after choosing the left-end packaging solution.
5. Weigh the complete moving selector. No density-derived mass was invented from the STEP files.
6. Verify harness bend/flex space throughout travel; the present wiring volume is provisional.
7. After a fit-check passes, home and address the first, middle, and last lane repeatedly. Characterize positional repeatability before calling the V-wheel stage production-ready; set the acceptance tolerance from the real TradRack filament-entry geometry rather than inventing one now.
8. Establish safe homing speed, switch overtravel, overshoot reserve, belt tension, and acceleration only after the physical checks.

## Verification record

- Design document reopened and recomputed: **PASS**.
- Groups, aliases, placements, arrays, and copied geometry persisted: **PASS**.
- Adapter: **one valid solid**, 14,471.748 mm³.
- Fit-check STEP: **one valid solid**.
- Fit-check STL: **solid mesh**, 960 facets, mesh volume 14,476.395 mm³.
- No production exports present: **PASS**.
- Source hashes unchanged: **PASS**.
- RPC used local loopback only: **PASS**.

| File | SHA-256 |
|---|---|
| `EnderRack_15Lane_Design.FCStd` | `5548FD411AB25CAA5D49DA87254DBB6143FCBED0504B2039C3418DE7E0B6E1D4` |
| `EnderRack_Interface_FitCheck.FCStd` | `6E27DB212DEC36AFD9EDEE3BF8660E55BE5FCD03E1C8D9B63AFBD4966D62D00E` |
| `exports/EnderRack_Interface_FitCheck.step` | `DFB476A0BD1112BF8C5DE84C189DD2B0EF29DAF8E8B0E3CC908E68EF272F5F87` |
| `exports/EnderRack_Interface_FitCheck.stl` | `6F96E7328E8FC8571B804113EB810008C07098645E74A027D379F70089975B3F` |

The source archive/STEP SHA-256 values remain `BE7646…71E8`, `19459C…BDB3`, and `D81BDE…B5D0`, matching the feasibility audit.

Complete parametric design

Lane array

First 15-lane extreme

Last 15-lane extreme

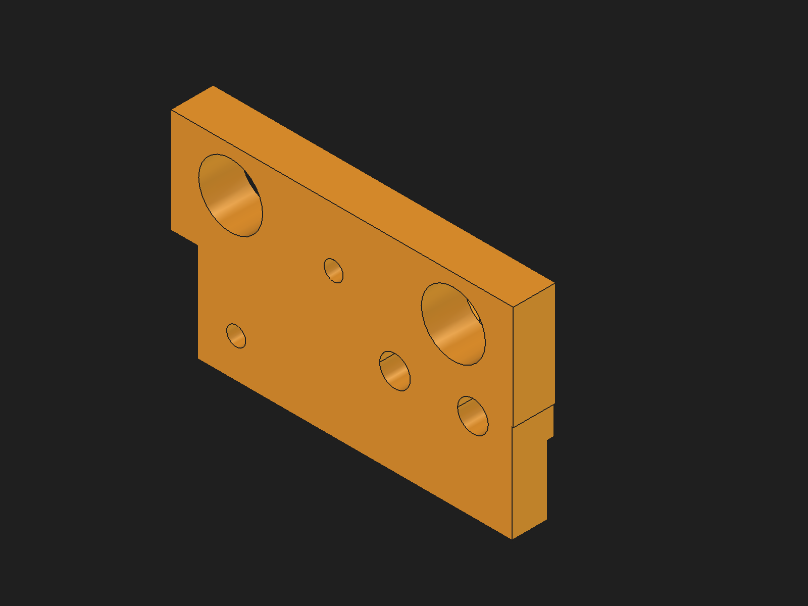
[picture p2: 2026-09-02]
evidence/renders/r5/CouponOnly_Isometric.png

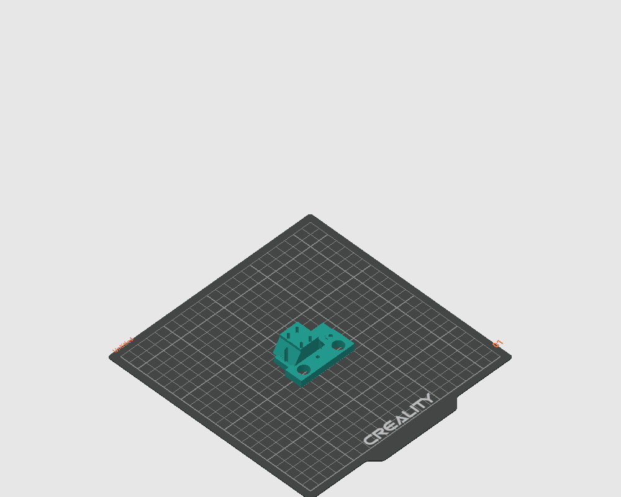
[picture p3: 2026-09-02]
evidence/renders/orca-r5-diagnostic/post-orient-iso.png

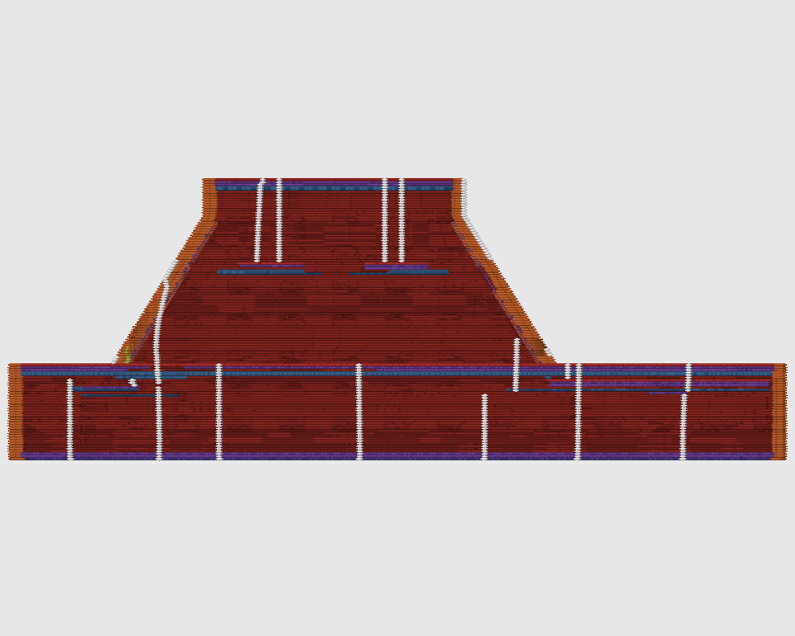
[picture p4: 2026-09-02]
evidence/renders/orca-r5-diagnostic/sliced-preview-front.png

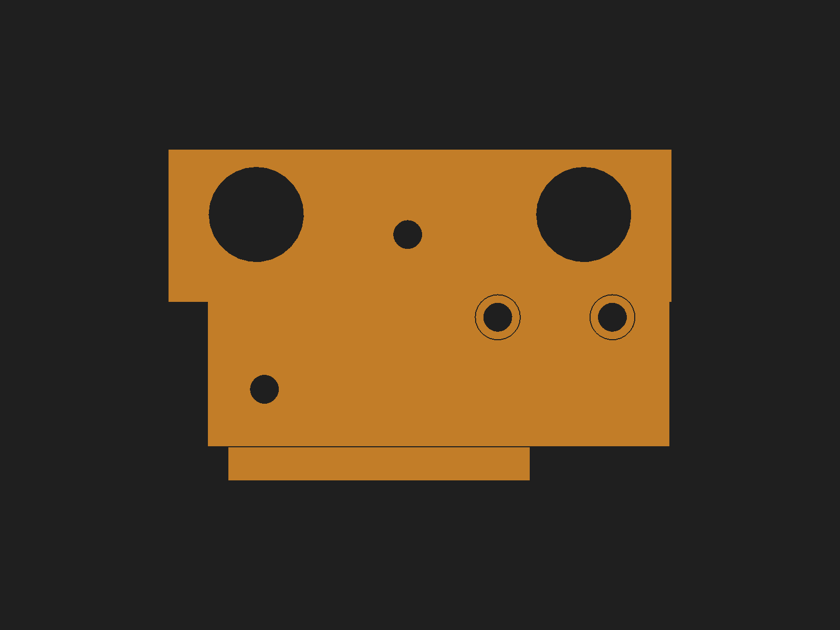
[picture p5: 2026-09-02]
evidence/renders/r5/CouponOnly_SteelContact.png

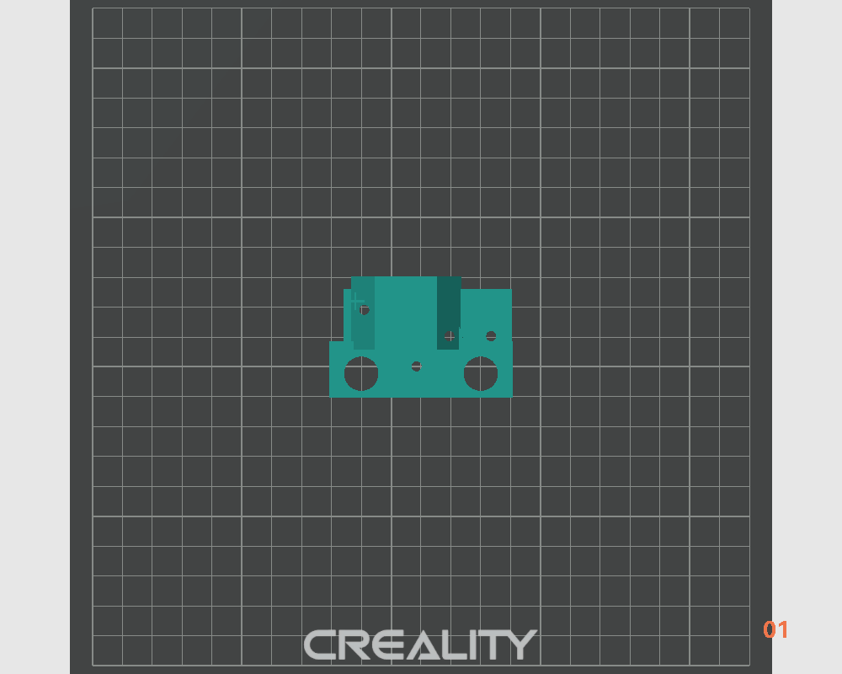
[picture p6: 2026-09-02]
evidence/renders/orca-r5-diagnostic/post-orient-top.png

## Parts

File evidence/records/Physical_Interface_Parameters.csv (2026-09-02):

Feature_ID | X_mm | Z_mm | Diameter_mm | Depth_mm | Feature_Type | Thread_Fastener | Front_Access | Rear_Access | Usable_For_Adapter | Datum_Reference | Measurement_Method | Repeatability_mm | Confidence | Notes
DATUM_U0 | 0 | 0 |  |  | Upper wheel axis | motor-side upper wheel |  |  |  | Y=0 outward steel face; origin | pin or axle measurement |  | pending | Defines origin
DATUM_U1 |  |  |  |  | Upper wheel axis | tensioner-side upper wheel |  |  |  | DATUM_U0; +X toward tensioner | pin or axle center-distance |  | pending | Defines X axis; expected near 40 mm only as a comparison, not an input
DATUM_ECC |  |  |  |  | Lower eccentric wheel axis | eccentric axle |  |  |  | DATUM_U0 | pin or axle measurement |  | pending
FACE_Y0 | 0 | 0 |  | 0 | Datum plane | steel outward face |  |  | no | DATUM_U0 | flatness and depth checks |  | pending
P01 |  |  |  |  | Unclassified feature |  |  |  |  | DATUM_U0 | pin/caliper plus calibrated scan |  | pending
P02 |  |  |  |  | Unclassified feature |  |  |  |  | DATUM_U0 | pin/caliper plus calibrated scan |  | pending
P03 |  |  |  |  | Unclassified feature |  |  |  |  | DATUM_U0 | pin/caliper plus calibrated scan |  | pending
P04 |  |  |  |  | Unclassified feature |  |  |  |  | DATUM_U0 | pin/caliper plus calibrated scan |  | pending
P05 |  |  |  |  | Unclassified feature |  |  |  |  | DATUM_U0 | pin/caliper plus calibrated scan |  | pending
P06 |  |  |  |  | Unclassified feature |  |  |  |  | DATUM_U0 | pin/caliper plus calibrated scan |  | pending
BELT_CENTER |  |  |  |  | Belt centerline |  |  |  | no | state extrusion face and axis explicitly | caliper/depth measurement |  | pending
BELT_CLAMP |  |  |  |  | Belt attachment |  |  |  | pending | DATUM_U0 | caliper plus photograph |  | pending
R2_BOSS_CLEARANCE_A | 43.5 | -12.55 | 5.5 | 5.2 | Boss clearance pocket | M3 bore coaxial | contact-side pocket | selector side through bore | yes | DATUM_U0; X toward tensioner; Z machine-up | official BRep center + R2 physical seating PASS |  | validated-fit | Clearance feature only; not a locator; physical boss OD/height not independently measured
R2_BOSS_CLEARANCE_B | 29.5 | -12.55 | 5.5 | 5.2 | Boss clearance pocket | M3 bore coaxial | contact-side pocket | selector side through bore | yes | DATUM_U0; X toward tensioner; Z machine-up | official BRep center + R2 physical seating PASS |  | validated-fit | Clearance feature only; not a locator; physical boss OD/height not independently measured
SELECTOR_MOUNT_FRAME | 15.0 | -20.3 |  | 22.25 | TradRack selector mating frame | 4 x temporary M3 on 10 x 15 pattern | selector-facing | tool approach from selector side | fit-check | Y=0 steel contact; X origin motor upper wheel; Z shown in Z_mm; depth column records +Y | official Ender/TradRack CAD + conservative local envelope |  | digital-provisional | T=(+15.000,+22.250,-20.300) mm; RPY=0/0/0; physical selector and belt check required

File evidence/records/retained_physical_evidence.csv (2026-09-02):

Measurement_ID | Value_mm | Datum_Reference | Method | Confidence | Status | Notes
PHYS_TRAVEL | 270 | same carriage-hole center; X switch just clicked to furthest safe opposite position | rough physical observation | medium-high | provisional | Preserved; refine to approximately +/-2 mm
TENSIONER_LENGTH | 45 | tensioner longitudinal extent; exact endpoints not recorded | small-ruler physical observation | low | provisional | Remeasure after carriage datum is established
TENSIONER_PROTRUSION | 7 | protrusion from an unrecorded reference face | small-ruler physical observation | low | provisional | Do not use until datum is restated
BELT_CENTERLINE | 10 | reference extrusion face and axis not yet recorded | physical observation | low | provisional | Remeasure with explicit datum
PULLEY_FROM_EXTRUSION_END | 10 | from extrusion end along X | physical observation | low-medium | provisional | Preserve and verify
TRADRACK_LANE_PITCH | 17 | official TradRack lane-center axis | official CAD measurement | high | reference | Unaffected
SPAN_15_LANES | 238 | 14 intervals at 17 mm | derived | high | derived | Unaffected
SPAN_12_LANES | 187 | 11 intervals at 17 mm | derived | high | derived | Unaffected

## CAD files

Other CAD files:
cad/working/EnderRack_Selector_Interface_Coupon_R5.FCStd
exports/fit-checks/Ender3_Official_Carriage_FitCheck_R2.step
exports/fit-checks/EnderRack_Selector_Interface_Coupon_R5.step
cad/fit-checks/Ender3_Official_Carriage_FitCheck_R2.FCStd
exports/fit-checks/Ender3_Official_Carriage_FitCheck_R2.stl
exports/fit-checks/EnderRack_Selector_Interface_Coupon_R5.stl

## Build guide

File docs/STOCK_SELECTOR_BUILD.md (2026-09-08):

# PRINT THESE NOW

**Controlling selection after the 2026-09-07 mod comparison: stock R1.** Binky and EREC remain UNVERIFIED against R7; see [MODDED_SELECTOR_COMPARISON.md](MODDED_SELECTOR_COMPARISON.md). Measure the user's spare Ender stepper and mirrored BMG-clone internals before purchasing the motor or genuine Bondtech parts below.

One stock moving selector: **9 mm belt / C-cart middle, 10x10 two-hole right carriage, Micro-Fit holder, FT1117M servo, conventional separate BMG gears**. These variant names preserve the authenticated default selector geometry; they do not require buying a TradRack belt, rail, or cable chain now. Twelve part files, one of each. No R7 redesign.

| Quantity | Exact upstream path | Exact filename | Upstream Git blob SHA | Purpose / source object | Color |
|---|---|---|---|---|---|
| 1 | `STLs/Selector/` | [`[a]_cable_cover_x1_rev7.STL`](https://github.com/Annex-Engineering/TradRack/blob/f89dc0b115adfc49195d782c5d7ecd348a574891/STLs/Selector/%5Ba%5D_cable_cover_x1_rev7.STL) | `140571e577abfeab2679fb898ef55ab8134c43ee` | Covers moving-selector wiring; `Part__Feature111` | Accent |
| 1 | `STLs/Selector/` | [`carriage_left_x1_rev7.STL`](https://github.com/Annex-Engineering/TradRack/blob/f89dc0b115adfc49195d782c5d7ecd348a574891/STLs/Selector/carriage_left_x1_rev7.STL) | `401ee7164cd9372d20329f8810b091074232d9c4` | Left pivot-bearing support; `Part__Feature102` | Primary |
| 1 | `STLs/Selector/` | [`carriage_middle_(9mm_belt)_(c_cart)_x1_rev15.STL`](https://github.com/Annex-Engineering/TradRack/blob/f89dc0b115adfc49195d782c5d7ecd348a574891/STLs/Selector/carriage_middle_%289mm_belt%29_%28c_cart%29_x1_rev15.STL) | `31a2311c419ace6ac7683d7cdd289e199d680218` | Authenticated middle / R7 mating body; `Part__Feature099` | Primary |
| 1 | `STLs/Selector/` | [`carriage_right_(10x10_cable_chain)_x1_rev8.STL`](https://github.com/Annex-Engineering/TradRack/blob/f89dc0b115adfc49195d782c5d7ecd348a574891/STLs/Selector/carriage_right_%2810x10_cable_chain%29_x1_rev8.STL) | `e8016568e451d526b00f543c30bc2056aadb4f88` | Right pivot / servo support; two-hole chain provision; `Part__Feature101` | Primary |
| 1 | `STLs/Selector/` | [`microfit_holder_x1_rev3.STL`](https://github.com/Annex-Engineering/TradRack/blob/f89dc0b115adfc49195d782c5d7ecd348a574891/STLs/Selector/microfit_holder_x1_rev3.STL) | `3d5ec22813f00473bdfee4b53f0cbf0efdc18810` | Holds three stock Micro-Fit plugs; `Part__Feature113` | Primary |
| 1 | `STLs/Selector/` | [`servo_horn_x1_rev2.STL`](https://github.com/Annex-Engineering/TradRack/blob/f89dc0b115adfc49195d782c5d7ecd348a574891/STLs/Selector/servo_horn_x1_rev2.STL) | `0b7d14fda51a0cd1a619637062ba3fe44a880674` | Servo lever and follower bearing; `Part__Feature110` | Primary |
| 1 | `STLs/Tilting Extruder Driver/` | [`[a]_arm_x1_rev5.STL`](https://github.com/Annex-Engineering/TradRack/blob/f89dc0b115adfc49195d782c5d7ecd348a574891/STLs/Tilting%20Extruder%20Driver/%5Ba%5D_arm_x1_rev5.STL) | `683d8696149dbb77143bc9182534e61740626bfa` | Filament idler arm; `Part__Feature036` | Accent |
| 1 | `STLs/Tilting Extruder Driver/` | [`gear_casing_left_x1_rev6.STL`](https://github.com/Annex-Engineering/TradRack/blob/f89dc0b115adfc49195d782c5d7ecd348a574891/STLs/Tilting%20Extruder%20Driver/gear_casing_left_x1_rev6.STL) | `6ccdeae7a1a0e41854b20976dccd71f570e63853` | Left drive housing; `Part__Feature034` | Primary |
| 1 | `STLs/Tilting Extruder Driver/` | [`gear_casing_right_x1_rev6.STL`](https://github.com/Annex-Engineering/TradRack/blob/f89dc0b115adfc49195d782c5d7ecd348a574891/STLs/Tilting%20Extruder%20Driver/gear_casing_right_x1_rev6.STL) | `7d79a1ad3e32006044670172ecafa985b4f5743f` | Right drive housing; `Part__Feature035` | Primary |
| 1 | `STLs/Tilting Extruder Driver/` | [`motor_plate_x1_rev5.STL`](https://github.com/Annex-Engineering/TradRack/blob/f89dc0b115adfc49195d782c5d7ecd348a574891/STLs/Tilting%20Extruder%20Driver/motor_plate_x1_rev5.STL) | `97ea6e0b9d4425b776c4bb4941a5b9bf10b8686d` | Filament-drive motor / pivot plate; `Part__Feature032` | Primary |
| 1 | `STLs/Tilting Extruder Driver/` | [`nema_17_spacer_x1_rev2.STL`](https://github.com/Annex-Engineering/TradRack/blob/f89dc0b115adfc49195d782c5d7ecd348a574891/STLs/Tilting%20Extruder%20Driver/nema_17_spacer_x1_rev2.STL) | `2336904b003c26371de4318fe698682214656d54` | Filament-drive motor spacer; `Part__Feature033` | Primary |
| 1 | `STLs/Tilting Extruder Driver/` | [`tensioner_collar_x1_rev1.STL`](https://github.com/Annex-Engineering/TradRack/blob/f89dc0b115adfc49195d782c5d7ecd348a574891/STLs/Tilting%20Extruder%20Driver/tensioner_collar_x1_rev1.STL) | `20fc9450cf8d03f7d75182b703d5c33fca996fee` | Spring adjuster on M3x30 screw; `Part__Feature075` | Primary |

## PRINT THESE TOOLS NOW

| Quantity | Exact upstream path | Exact filename | Upstream Git blob SHA | Color |
|---|---|---|---|---|
| 1 | `STLs/Tools/` | [`[a]_servo_jig_horn_angle_x1_rev2.STL`](https://github.com/Annex-Engineering/TradRack/blob/f89dc0b115adfc49195d782c5d7ecd348a574891/STLs/Tools/%5Ba%5D_servo_jig_horn_angle_x1_rev2.STL) | `af2bcdd9f9bb852844f6eebae7af2b4839d0b3e3` | Accent |
| 1 | `STLs/Tools/` | [`[a]_servo_jig_up_angle_x1_rev1.STL`](https://github.com/Annex-Engineering/TradRack/blob/f89dc0b115adfc49195d782c5d7ecd348a574891/STLs/Tools/%5Ba%5D_servo_jig_up_angle_x1_rev1.STL) | `bddf8b02fa0fe7e56227f37a834ecbd17275e0e7` | Accent |

These two jigs are required by the upstream servo-angle procedure linked from Quick Start. Print with the parts; use during later deliberate servo calibration, not by forcing an unpowered servo. They are tools, not assembly members. Do not print the MGN installation guide for this build.

## Official print specification

The pinned [Print_Settings_and_File_Key.txt](https://github.com/Annex-Engineering/TradRack/blob/f89dc0b115adfc49195d782c5d7ecd348a574891/Print_Settings_and_File_Key.txt) is controlling here: 0.4 mm nozzle; ASA recommended (PC approved alternative); 0.20–0.25 mm layers; 0.40–0.45 mm extrusion width; at least 40% infill (source qualifies this at 0.6 mm infill width); Grid, Gyroid, Honeycomb, Triangle or Cubic; at least four walls (at 0.4 mm width); at least four top and bottom layers (source qualifies this at 0.25 mm layer height). Preserve those qualifications when choosing an actual profile. No XY/hole shrink compensation; elephant-foot compensation is allowed.

`[a]_` means accent color; no prefix means primary; `_x#` is required quantity; `_rev#` is file revision. PLA is **not** listed as stock-approved. Do not reuse the PLA R7 coupon profile. This task does not establish that the current Aquila configuration is suitable for ASA/PC or supply temperatures for it. The older build PDF p5 has different process advice; the expressly requested pinned print-spec file above governs this sheet, rather than silently mixing the two.

## BUY NOW — STOCK SELECTOR

Installed quantities, not package sizes; buy spares at your discretion. The official spreadsheet is for an entire TradRack. These are selector-only allocations reconciled with PDF pages 24–44 and 58 and the source object inventory. Included kit items count toward totals, not in addition.

| Quantity | Exact item/spec | Used in | Upstream BOM row/category | Buy now? | Notes |
|---|---|---|---|---|---|
| 1 | NEMA17 filament-drive motor, 1.8°, stock target LDO-42STH48-2504AC | Filament drive | 24 Motion/Common | **HOLD — MEASURE SPARE ENDER MOTOR** | 48 mm body in stock source; NOT selector-motion motor. Buy only if reuse check fails. |
| 1 | Bondtech BMG 17T motor gear | Motor shaft | 15 Motion/Common | **HOLD — MEASURE CLONE PART** | Retain locking screw; not the 20T motion pulley. Buy only if tooth count, bore and axial alignment fail. |
| 1 set | Bondtech drive gear set, 1.75 mm filament / 5 mm primary bore | Primary gear + idler | 17 Motion/Common | **HOLD — MEASURE CLONE PARTS** | Include two idler needle bearings and primary-gear set screw. Do not buy an IDGA replacement before comparison. |
| 1 | Bondtech original BMG main shaft assembly, 50T geared shaft | Filament reduction | 18 Motion/Common | **HOLD — MEASURE CLONE STACK** | Original separate-gear BMG assembly, manufacturer 15021. Internal-shim/stack equivalence UNRESOLVED; do not substitute integrated/short-shaft kits. |
| 1 | Bondtech BMG thumbscrew assembly | Idler preload | 19 Motion/Common | **HOLD — INSPECT CLONE** | Reuse candidate is spring and plastic washer; stock build replaces the thumbscrew itself with M3x30 + printed collar. |
| 1 | 3 x 20 mm shaft, G6 external fit, 1045 steel | Idler gear | 16 Motion/Common | **HOLD — MEASURE CLONE SHAFT** | One total; often included in drive-gear set, do not double-buy. |
| 2 | MR85-2RS bearings, 5 x 8 x 2.5 mm | Main gear shaft | 20 Motion/Common | YES | One each side; kit contents count toward two only if correct spec. |
| 2 | MR115-2RS bearings, 5 x 11 x 4 mm | Tilting mechanism pivots | 21 Motion/Common | YES | One in each carriage side. |
| 1 | 623-2RS bearing, 3 x 10 x 4 mm | Servo-horn follower | 22 Motion/Common | YES | Only one selector bearing; lane bearings excluded. |
| 1 | 5 x 40 mm shaft, G6 external fit, 1045 steel | Tilting pivot | 26 Motion/Common | YES | Not the stationary idler 5x30 shaft. |
| 1 | FEETECH MINI FT1117M servo | Tilting actuation | 25 Motion/Common | YES | Exact selected stock model, source Part__Feature085. No menu of servo substitutes. |
| 1 | 4 mm steel ball | Selector filament sensor | 29 Motion/Common | YES | Retain in middle carriage; PDF p27. |
| 1 | ECAS-04 push-fit connector | Selector output | 39 Other mechanical | YES | Selector count one; lane connectors excluded. |
| 1 | Omron D2F-L-D3 lever microswitch | Selector filament detection | 43 Electronics | YES | D2F-L class required; source lever-switch label. No second motion-endstop switch. |
| 4 | Shim washers, 5 ID x 7 OD x 0.5 mm, spring steel | Pivot and casing stack | 93 Hardware | YES | Standalone source 071–074; distinct from internal shaft-assembly shim. Assemble/check per PDF pp35–39; do not force a binding stack. |
| 12 | M3 short brass heat-set inserts, D5 x L4 mm | Active selector joints | 95 Hardware | YES | 3 motor plate + 1 arm + 2 servo support + 4 middle-side joints + 1 horn + 1 cover. Excludes 2 chain and 3 optional-board inserts. |
| 1 | M3 x 30 socket-head cap screw | Spring adjuster | 84 Hardware | YES | Source153; second whole-machine screw excluded. |
| 3 | M3 x 25 socket-head cap screws | Gear casing clamp | 85 Hardware | YES | 157–159. |
| 2 | M3 x 16 socket-head cap screws | Upper servo/Micro-Fit holder + cable cover | 86 Hardware | YES | 170,180; holder shares the upper servo fastener. |
| 6 | M3 x 10 socket-head cap screws | Motor(3), horn(2), lower servo(1) | 88 Hardware | YES | 154–156,162–163,171. |
| 4 | M3 x 8 socket-head cap screws | Left/right carriage joints | 90 Hardware | YES | 172–175 only; NOT four rail screws or lane roller screw. |
| 1 | M2.5 x 5 servo spline screw | Horn retention | 91 Hardware | YES if not supplied | 164; check supplied servo screw engagement, never bottom it. Upstream permits 4 mm too; selected nominal is 5 mm. |
| 2 | M2 x 12 pan-head self-tapping screws | Filament microswitch | 92 Hardware | YES; CAD-label caveat below | PDF p29 and BOM agree; source176–177 generic CAD names differ. |
| 4 | M3 plain narrow washers | Motor(3), horn clamp(1) | 94 Hardware | YES | 199–202. |
| 1 each | Molex Micro-Fit 3.0 plugs: 43640-0401, 43640-0301, 43640-0201 | 4/3/2-position holder | 76–78 Wiring | YES | Three housings, source117–119; stock no-PCB wiring arrangement. |
| 1 each | Molex Micro-Fit 3.0 receptacles: 43645-0400, 43645-0300, 43645-0200 | Mating local lead housings | 73–75 Wiring | YES | Three housings, source114–116. |
| 9 each | Micro-Fit male contacts 43031-0007; female contacts 43030-0007 | 4+3+2 circuits | 71–72 Wiring | YES | 18 contacts total. Whole-machine BOM has 12 each; selector-only has 9 each. |

### Procurement and assembly limits — do not guess

- **R7 mounting screws: UNRESOLVED length/engagement.** Four selector mounting positions remain, but stock MGN M3x8 screws are not automatically correct for R7's provisional blind pilots. Measure the real selector counterbore/grip and available R7 engagement before choosing these four screws. Do not drive until bottoming, drill through, retap, or change R7 as part of this task. Existing R7-to-Ender fasteners remain in use; the donor has never been taken apart for this task.
- **BMG source detail:** the default CAD uses a `sherpa_mini_gear_50t_sl_7mm` occurrence and a separate 0.5 mm internal shim. Its gear solid is invalid and remains UNVERIFIED. The BOM and manual call for the conventional BMG shaft assembly. Manufacturer [15021](https://www.bondtech.se/product/shaft-assembly/) confirms that original assembly, not a modern integrated replacement. Exact internal-shim supply and dimensional equivalence to the source Sherpa-named subassembly are **UNRESOLVED**; ask the supplier to confirm the complete original assembly contents before ordering a substitute or a bare shaft. The four standalone 5x7 shims above do not silently replace this internal shim. A current Sherpa internals kit is not authenticated as an interchangeable purchase.
- **Microswitch screw CAD catalog label:** source says `PHT 2x13x12.2`, whereas the BOM and build instruction explicitly specify M2x12. The table follows the two explicit procurement/assembly sources; the catalog-label dimensional discrepancy remains UNRESOLVED, not a claimed exact CAD match.
- **Inserts:** the default contains 17 moving-root insert occurrences. Twelve serve this immediate build; two are chain attachment and three optional board attachment. Install active inserts only; do not infer that the right-carriage label “With Breakout Board” requires buying a PCB. The selected source actually contains the six Micro-Fit housings. Generic long kit inserts are not the specified short D5xL4 inserts.
- Local switch leads and consumables are needed to complete wiring, not to prove static fit. Upstream wiring guidance gives approximate cut lengths (motor 210 mm, servo 170 mm, switch 155 mm); dry-route before cutting. Use motor/servo supplied leads and two switch leads; exact purchased wire length, heat-shrink size and final harness length are **UNRESOLVED until routed**, not a made-up selector BOM quantity. No controller hookup or powered calibration in this task.

## ALREADY PROVIDED BY ENDER

The intact Ender X extrusion, V-wheel carriage/complete wheel stack, belt, X motor and drive, idler/tensioner/end hardware, and endstop provide selector translation. The original Ender X-axis hardware remains assembled/in place. This is separate from the Aquila used to print the R7 coupon.

## REUSE CHECK — DO THIS BEFORE BUYING MOTOR OR BMG PARTS

The two mirrored/reverse BMG housings are irrelevant if their removable internals match. Record both clones separately; do not assume they contain identical parts.

| Candidate | Measure/inspect | Acceptance comparison |
|---|---|---|
| spare Ender stepper | 42 mm face; mounting-hole center spacing; shaft diameter; shaft protrusion from face; body depth; connector/pin order; rated current/phase; smooth shaft/bearing condition | Must match NEMA17 mounting, 5 mm motor-gear bore and the stock 48 mm envelope/gear alignment without R7 or selector interference. Torque/current suitability must be supported by the motor label/datasheet, not appearance. |
| 17T motor pinion | tooth count; 5 mm bore; face width; set-screw presence/condition; installed axial position range | Must mesh with the 50T gear at the stock motor spacing and retain securely on the spare motor shaft. |
| primary hob/50T geared shaft | 50T gear; 5 mm bearing journals; hob diameter and groove; overall/shoulder lengths; set screw; runout/damage | Compare the complete axial stack to the official conventional BMG shaft assembly. Do not approve a short/integrated shaft by gear appearance alone. |
| idler drive gear | 3 mm needle-bearing bore; hob diameter/groove alignment; width; tooth profile; damage | Must accept the 3 x 20 pin and two needle bearings and align its filament groove with the primary hob. |
| needle bearings | quantity two; fit on 3 mm pin; OD/length; smoothness/play | Both must fit the idler gear without binding or visible corrosion/brinelling. |
| 3 mm pin | diameter at several points; length; straightness and surface finish | Target is 3 x 20 mm; reject bent/scored or loose parts. |
| spring/plastic washer | spring OD, wire diameter, free length and damage; washer ID/OD/thickness | Compare physically with the BMG thumbscrew preload stack; reuse only if it seats squarely and gives usable adjustment with M3x30/collar. |
| MR85 bearings if present | markings or measured 5 x 8 x 2.5 mm; smoothness/play | Two required for the main shaft; clone bearings are reusable only if dimensionally correct and smooth. |

Photograph the motor label and lay the measured internals beside calipers. Do not buy genuine Bondtech parts or a new filament-drive motor until this table is completed. Binky could later reuse the idler gear, two needle bearings, 3 x 20 pin and spring, but that does not justify printing Binky before its R7 result is resolved.

## DO NOT BUY

For this EnderRack selector build: stock TradRack MGN9 rail/cart and its four M3x8 mounting screws; selector-motion NEMA17 (BOM23); 6/9 mm selector-motion belt, 20T drive pulley and idler; stationary idler 5x30 shaft; stationary selector motor mount, rail stops, original tensioner; belt-anchor M3x12; separate stock motion-endstop switch. Do not print their associated stationary parts. These exclusions do **not** remove the filament-drive NEMA17, BMG motor gear, tilting bearings, or servo.

## BUY LATER — FULL ENDERRACK

Lane-bank modules, lane bearings/rollers/ECAS connectors and fasteners, 15-lane stationary hardware, buffers, output Bowden tubing to measured length, controller and final harness, cable chain/end attachments (two M3 countersunk x10 and two inserts on the selector end), stationary cable routing and production hardware. Optional breakout PCB and its three inserts are not needed by the chosen Micro-Fit build. Do not buy the whole-machine quantities now.

## ASSEMBLE — stock selector only, no powered motion

1. Print the twelve parts and two tools in the official stock material/process. Inspect holes and remove support/first-layer defects without changing interfaces. Lay out hardware. Prepare the 12 active short inserts in their mapped parts; follow PDF pp24,30,35,40,42. Do not insert the five deferred chain/board inserts just because CAD contains them.
2. Bench-assemble the middle with the 4 mm ball, the lever filament switch and two M2x12 screws (pp27–29). Solder to the outer switch terminals before installation if preparing its leads. Do not perform the manual's MGN rail mounting steps.
3. Press one MR115 into the left carriage and join left to middle with two M3x8 (pp29–30). Prepare the motor plate with its three inserts and one MR85.
4. Fit the 5x40 pivot shaft to the motor plate, approximately 6 mm rear protrusion per p31. Attach the filament motor and spacer using three M3x10 and three washers.
5. Assemble the conventional BMG geared shaft, primary filament gear and 17T motor pinion (p32). Retain the correct set screws; establish alignment, not force. Resolve the internal-shim procurement caveat before completing that stack.
6. Fit left casing, 3x20 shaft, two needle bearings and secondary/idler gear (pp33–34). Add arm, shims and right casing/MR85 in the sequence of pp35–36. Four standalone shims are available; the manual treats a casing shim as optional depending on fit. Do not force all shims into a binding mechanism.
7. Clamp casing with three M3x25, adjust motor gear mesh for free movement, then fit spring and BMG plastic washer on M3x30 with printed tensioner collar (pp37–38). Do not use the kit's thumbscrew instead of the collar construction.
8. Fit the tilting unit and pivot shim into the left bearing; fit right MR115 and right carriage, attaching with two M3x8 (pp39–41). Check free pivoting.
9. Assemble printed horn with its insert, M3x10 clamp screw/washer and 623 bearing on the other M3x10 (p42). Install FT1117M with lower M3x10 and upper M3x16 shared with the Micro-Fit holder (pp43–44). Retain the selected M2.5x5 spline screw but do not force horn angle; final angular setting needs the upstream jigs/calibration later.
10. Fit the three plug housings into the holder and their mating receptacles as required. Install ECAS output and cable cover with its M3x16 (p58). Leave chain, optional PCB and controller wiring out. Check drive rotation, idler movement, sensor-ball action and tilting movement by hand without forcing the servo gears.
11. Keep R7 on the intact Ender carriage: seat R7, then tighten its carriage fasteners before attaching the selector. Resolve four R7 selector-screw lengths/engagement as noted above; do not assume stock rail screws work. Attach the complete selector finger-snug only.
12. Record carriage seating/four-hole alignment; selector mount/orientation; measured real stand-off; rocking, translation, rotation; wheel/eccentric and real belt/clamp clearance; fastener/tool access; light hand-load stiffness. Do not power motion. Only the complete scoped R7 physical result can unlock production and the 238 mm sweep.

## Three-way reconciliation and provenance

Authority: [pinned Quick Start](https://github.com/Annex-Engineering/TradRack/blob/f89dc0b115adfc49195d782c5d7ecd348a574891/docs/Quick_Start.md), [mechanical build PDF](https://github.com/Annex-Engineering/TradRack/blob/f89dc0b115adfc49195d782c5d7ecd348a574891/docs/build_instructions/TradRack_Build_Instructions_Beta_A0.1.pdf), [STL variant key](https://github.com/Annex-Engineering/TradRack/blob/f89dc0b115adfc49195d782c5d7ecd348a574891/STLs/README.md), and the [official BOM linked by Quick Start](https://docs.google.com/spreadsheets/d/1SKBtkgSVPqqGEjftI6v6i6T5Bh3Phx-4YXsJYH17ggs/edit). Upstream commit is `f89dc0b115adfc49195d782c5d7ecd348a574891`. The BOM is a live external sheet, not frozen by that Git commit; this document uses its 2026-09-04 XLSX snapshot, with hash below. No community BOM was used.

The source is `trad_rack_(default).STEP`, root `Moving_Extruder_MMU_V3_No_Extrusion`. Object IDs refer to the existing authenticated reference import, **not** unstable regenerated IDs. Source/root/object inventory and snapshot hashes are in [selector source evidence](reports/STOCK_SELECTOR_SOURCE_EVIDENCE.json).

- Middle: `Part__Feature099`, “Carriage - Middle”, explicitly 9mm Belt/C-Cart. Print precisely the table's matching variant. Tiny residual `Part__Feature100` is not a second printed part.
- Right: `Part__Feature101` has the two-hole chain attachment (8 mm axis spacing) and two source chain screws178–179. The pinned variant key assigns the two-hole pattern to 10x10, versus three-hole 10x11. Corroboration: CAD volume 12860.014 mm³; 10x10 mesh 12860.333; 10x11 mesh 12779.177. Volume is corroboration, not proof of full export equivalence. Print only the 10x10 right carriage; do not buy its future chain yet.
- Printed membership: the twelve object mappings in the table; the two tools derive from upstream calibration instructions, not CAD membership. No stationary lane/rail prints.
- The prior 156-component installed collision set is **not** a quantity oracle. It includes individual internal motor/servo components, and some stage/accessory hardware needs functional classification. For example, source160 is a lane roller screw;165–168 are MGN mounting screws;169 is the belt anchor;178–179 are chain screws. None is an additional selector-body purchase in the table.
- Hardware placements and source names corroborate the manual's selector-specific counts. Four M3x8 side fasteners are172–175; six M3x10 are154–156,162–163,171; two M3x16 are170,180; three M3x25 are157–159; one M3x30 is153. Four external shims071–074 all have 0.5 mm axial thickness: duplicate label suffixes `.001/.002/.003` are not thinner washer specifications.
- This is a parts/assembly reconciliation, not a new CAD conformance or whole-master reproducibility audit. Invalid gear002 stays UNVERIFIED. Earlier whole-assembly claims remain subject to the upgraded-skill audit caveat in [CURRENT_STATE](CURRENT_STATE.md).

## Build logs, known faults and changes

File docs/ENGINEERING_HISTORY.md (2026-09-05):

# EnderRack engineering history

Current 2026-09-04 status: R7 V2 printed, scoped carriage fit PASS, full selector fit NOT TESTED. See [current state](CURRENT_STATE.md). Historical R5/22.25 mm conclusions below are retired; broad master/reproducibility claims need re-audit.

This document records engineering events that occurred before this directory entered Git. They are not represented as retrospective Git commits.

## 1. Ender-3 V2 source rejected

A community `Creality-Ender3-V2-rev4.STEP` assembly was imported and used for early feasibility and interface work. A physical coupon did not match the donor carriage. Subsequent machine identification established that the donor was not mechanically a V2. V2-derived fabricated-fit work was rejected and archived.

## 2. Official original Ender-3 source adopted

Official Creality Ender-3 CAD at commit `88c7758cea9d0d00a54fdb238bedb3b33425f409` was imported through FreeCAD MCP. The import contained 1,243 objects and passed null-geometry, topology, placement, save/reopen, and recompute checks. The official X gantry and `E plate` were isolated.

## 3. Official E-plate R2 physical carriage fit PASS

The first official-CAD coupon correlated the hole pattern but could not seat over two retained hotend bosses. R2 added clearance pockets and physically fit the real plate. The official E plate was promoted only for the interface features exercised by R2.

## 4. Secondary selector-interface digital PASS

The carriage-to-selector interface was rebuilt from the validated reference. Revisions corrected an overhang/load path and a weak wheel-edge ligament. R5 provides 5 mm lateral and lower wheel-relief ligaments, two full-height triangular gussets, and four blind temporary selector pilots.

## 5. Current gate pending

R5 is digitally valid but has not passed the real-selector physical test. The available G-code is diagnostic only because it used a V2 printer preset and carries an Orca material-temperature warning. Correct profile selection and re-slicing precede the physical test.

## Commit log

2026-09-02 Import EnderRack engineering history through R5
    [Ender3_Official_Carriage_FitCheck_R2.FCStd, Ender3_Official_Carriage_FitCheck_R2.step, Ender3_Official_Carriage_FitCheck_R2.stl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]
2026-09-05 Document scoped R7 V2 carriage fit and reconcile stock selector build
